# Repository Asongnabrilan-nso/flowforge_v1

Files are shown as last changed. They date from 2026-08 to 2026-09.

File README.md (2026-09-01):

# FlowForge

**Demo Video**

Demo (https://youtu.be/iGiAu_VeJ9w)

**An open-source 3D printing pen built entirely from waste.**

A handheld filament extrusion pen assembled from parts rescued from a decommissioned FDM 3D printer — hot end, nozzle, extruder mechanism, NEMA 17 stepper, PTFE tube and the printer's own Arduino Mega + RAMPS controller — and fed with filament drawn from discarded PET bottles. Every printed structural part is designed to print on the same recycled filament the pen itself consumes.

Waste plastic becomes a tool that draws in waste plastic.

## Repository layout

| Path | Contents |
|---|---|
| `firmware/` | PlatformIO project — Arduino Mega 2560 + RAMPS 1.6. See [`firmware/README.md`](firmware/README.md) |
| `stl/` | Printable parts: electronics unit enclosure and pen assembly |
| `doc/` | Project documentation and publication plan |

## The system

<p align="center">
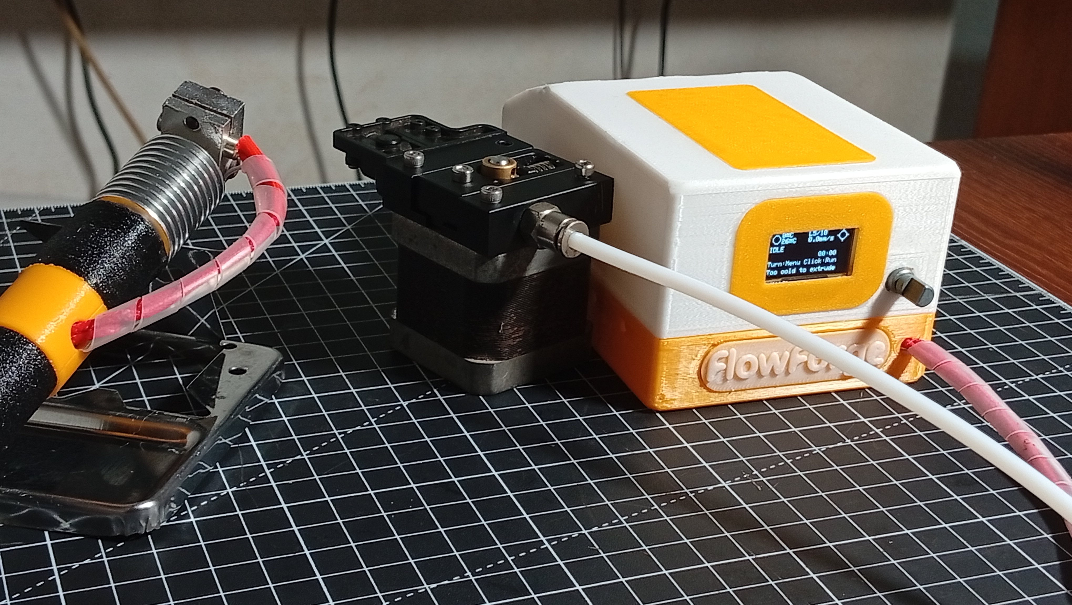
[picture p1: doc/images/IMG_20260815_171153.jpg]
  
</p>

Three units, not one object:

1. **The pen** — hot end, nozzle and vented barrel in a heat-isolated handle. No electronics beyond the heater cartridge, thermistor and fan.
2. **The electronics unit** — a 120 × 80 mm desktop wedge housing the Mega + RAMPS, the extruder stepper and driver, the OLED and the rotary encoder. Filament enters at the rear and leaves through a PTFE tether to the pen.
3. **A 24 V bench supply.**

## Sample products printed uinsing our filaments
<p align="center">
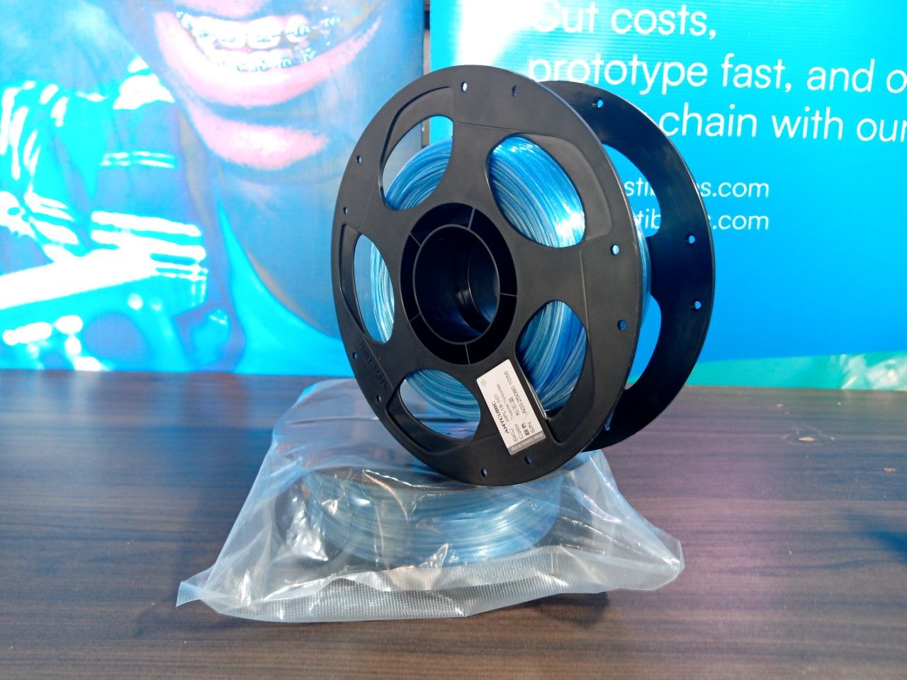
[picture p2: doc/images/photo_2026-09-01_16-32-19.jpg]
  
</p>

<p align="center">
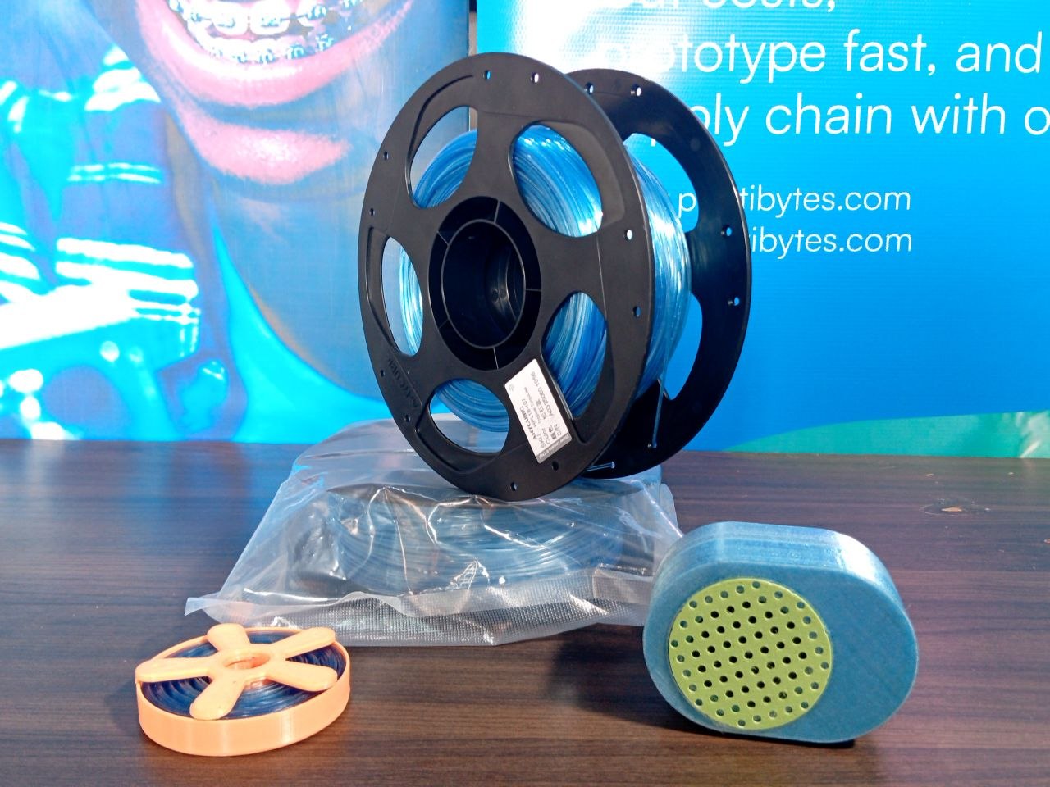
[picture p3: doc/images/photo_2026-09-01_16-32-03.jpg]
  
</p>

<p align="center">
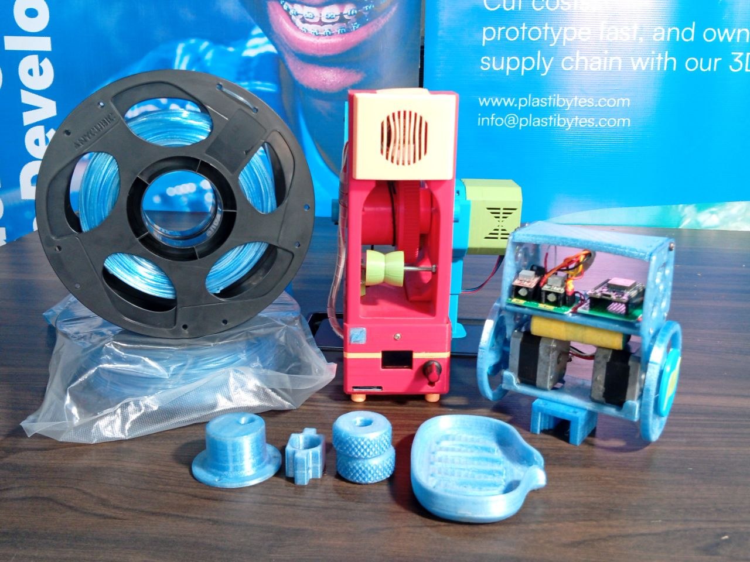
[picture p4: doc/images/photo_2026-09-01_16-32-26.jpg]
  
</p>

## Firmware at a glance

Closed-loop PID hotend control with Marlin-style thermal-runaway protection, an acceleration-ramped extruder, and a single-knob menu UI on a 128 × 64 OLED.

```sh
cd firmware
pio run              # build
pio run -t upload    # build + flash over USB
```

Safety behaviour worth knowing before you power one on:

- **The machine boots idle** — target 0 °C, motor disabled. Nothing heats until you set a target.
- **The motor will not start below 170 °C** (cold-extrusion interlock).
- **Four independent thermal faults latch until power cycle**: sensor open/short, over-temperature ceiling (260 °C), no-rise watchdog while heating, and post-settle drift watchdog.
- **Long-press the encoder from anywhere** for an immediate motor stop.

Full detail in [`firmware/README.md`](firmware/README.md).

## Licence

CERN-OHL-S v2 (hardware) · MIT (firmware).

## Status

Pre-publication. The documentation carries **[MEASURE]** markers wherever bench data is still outstanding — see the *Document maintenance* section at the end of `doc/flowforge-documentation.md` for the current list of unresolved items.

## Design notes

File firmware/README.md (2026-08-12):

# FlowForge Firmware

Firmware for a hand-built plastic-bottle-extruder machine: Arduino Mega 2560
+ RAMPS 1.6, one hotend (thermistor + PID-controlled heater cartridge), one
E0 stepper (A4988) feeding the extruder screw/gear, an SSD1306 128x64 OLED,
and an HW-040 rotary encoder for input.

The temperature control and menu/display are deliberately modeled on
Marlin's approach (PID shape, thermal-runaway watchdogs, hierarchical
click-to-navigate menu, status-screen layout) collapsed down to what this
single-hotend, single-motor machine actually needs — this is a small
hand-rolled firmware, not a Marlin build.

## Safety-relevant behavior (read this first)

- **The machine boots idle.** On power-up the heater target is 0°C (room
  temperature) and the motor is disabled. Nothing heats or moves until the
  operator explicitly sets a target (Temperature menu or a preheat preset)
  and/or starts the motor. If you're used to an earlier build of this
  firmware that auto-heated to 200°C on boot, that behavior has been
  removed.
- **Cold-extrusion interlock.** The motor will not start (click on Home is
  ignored, with a short "no" beep) unless the hotend is at or above
  `TEMP_MIN_EXTRUDE_C` (170°C by default, `include/config.h`).
- **Thermal runaway watchdogs** (mirrors Marlin's approach): while actively
  heating, the temperature must rise by `WATCH_INCREASE_C` every
  `WATCH_PERIOD_MS`, or it's treated as a heater/thermistor fault. Once
  settled, if the reading drifts more than `RUNAWAY_MAX_DEVIATION_C` from
  target for longer than `RUNAWAY_TIMEOUT_MS`, that's also a fault (stuck
  heater / thermistor fell out). An open/shorted thermistor and exceeding
  `TEMP_MAX_C` (260°C) are also immediate faults.
- **A FAULT is latched.** The display shows a full-screen alert, the heater
  and motor are forced off, and the *only* way out is a power cycle — this
  is intentional, not a bug.
- **Long-press the encoder, from anywhere, to immediately stop the motor**
  (it does not touch the heater). This works even mid-menu.

## Hardware wiring (`include/pins.h`)

| Signal | Pin | Notes |
|---|---|---|
| E0 STEP | D26 | RAMPS E0 driver slot (A4988) |
| E0 DIR | D28 | |
| E0 ENABLE | D24 | active LOW (LOW = driver enabled) |
| Hotend heater | D10 | MOSFET output; software-PWM driven, see below |
| Hotend thermistor | A13 | RAMPS T0 analog input, 4.7kΩ series divider |
| OLED SDA/SCL | D20/D21 | hardware I2C (Wire), address `0x3C` |
| Encoder A / B | D35 / D37 | HW-040 quadrature, polled (not interrupt-driven) |
| Encoder button | D31 | active LOW |
| Buzzer | D33 | `tone()`, Timer2 |

The heater is driven by a slow **software PWM window** (not `analogWrite`)
because pin 10 shares Timer2 with the Arduino core's `tone()` used for the
buzzer — see the comment in `src/Heater.h` for details. The encoder is
**polled** every `loop()` iteration rather than interrupt-driven, because
its pins (PORTC on the Mega2560) don't support pin-change interrupts — see
`src/Encoder.h`.

## Build & flash

This is a [PlatformIO](https://platformio.org/) project.

```sh
pio run                 # build
pio run -t upload       # build + flash over USB
pio device monitor       # serial monitor (115200 baud) - only used for a
                          # boot-time warning if the OLED doesn't ACK on I2C
```

Libraries (`platformio.ini`): Adafruit SSD1306, Adafruit GFX, Adafruit
BusIO — PlatformIO fetches these automatically on first build.

## Menu map

```
Home (status screen)
 |-- rotate  -> Main Menu
 |-- click   -> start/stop the extruder motor (instant, only if hot enough)
 `-- long-press (from anywhere) -> immediate motor stop

Main Menu
 |-- Back           -> Home
 |-- Temperature     -> Temperature Menu
 |-- Motor Speed     -> Set Motor Speed (edit screen)
 `-- Settings        -> Settings Menu (read-only)

Temperature Menu
 |-- Back            -> Main Menu
 |-- Nozzle           -> Set Temperature (edit screen)
 |-- Preheat PET      -> sets target to PREHEAT_PET_C (250C) immediately
 |-- Preheat HDPE     -> sets target to PREHEAT_HDPE_C (200C) immediately
 `-- Cooldown         -> sets target to 0

Settings Menu (read-only calibration readout)
 |-- Back            -> Main Menu
 |-- Steps/mm         -> EXTRUDER_STEPS_PER_MM
 |-- Max speed        -> EXTRUDER_FEEDRATE_MAX_MM_S
 `-- Accel            -> EXTRUDER_ACCEL_MM_S2

Set Temperature (edit screen)
 |-- rotate  -> adjust target by TEMP_STEP_C, clamped [0, TEMP_MAX_C]
 `-- click   -> confirm, return to Temperature Menu

Set Motor Speed (edit screen)
 |-- rotate  -> adjust speed level, clamped [SPEED_LEVEL_MIN, SPEED_LEVEL_MAX]
 `-- click   -> confirm, return to Main Menu
```

Every menu's row 0 is always **Back**, one level up — the top-level Back
(Main Menu) returns to Home. Every screen but Home is reached only by
rotating into the menu; **Home's click always toggles the motor directly**
and never enters the menu — this is a deliberate shortcut for fast,
glove-friendly start/stop on a handheld device, kept even though it departs
from Marlin (which only starts jobs through a menu action).

## Motor calibration (steps/mm)

The extruder speed is expressed in real units (mm/s of filament fed),
computed from `EXTRUDER_STEPS_PER_MM` in `include/config.h`. The shipped
default (500 steps/mm) is a **placeholder** — it depends on your motor's
steps/rev, the A4988 microstepping set by the RAMPS jumpers, and your
gear/pulley ratio, none of which this firmware can know on its own.

To calibrate:
1. Go to **Main Menu → Motor Speed** and set a known level (level 5 is a
   good midpoint).
2. Start the motor from Home (heat up past `TEMP_MIN_EXTRUDE_C` first) and
   let it run for a fixed, measured time — e.g. exactly 60 seconds — then
   stop it.
3. Measure how much filament actually came out, in mm.
4. Compute the commanded distance for that run: `commanded_mm =
   levelToFeedrateMmS(level) * seconds_run` (with the defaults, level 5 ≈
   2.0mm/s, so 60s ≈ 120mm commanded).
5. Rescale: `new_steps_per_mm = EXTRUDER_STEPS_PER_MM * (commanded_mm /
   measured_mm)`. Update `EXTRUDER_STEPS_PER_MM` in `config.h` and reflash.

`EXTRUDER_FEEDRATE_MIN_MM_S`/`_MAX_MM_S` are deliberately conservative out
of the box — they were chosen to keep the step-interrupt rate identical to
what this firmware already ran at before this update (200–2000 steps/sec),
not Marlin's own much higher extruder defaults. Once steps/mm is calibrated
and you've confirmed the motor tracks cleanly at the current ceiling, you
can raise `EXTRUDER_FEEDRATE_MAX_MM_S` (and `EXTRUDER_ACCEL_MM_S2` if you
want a snappier ramp) — increase gradually and watch/listen for missed
steps or stalling at the top of the range before committing to a value.

## PID tuning

`include/config.h`'s `PID` section documents each constant inline
(`PID_KP`/`PID_KI`/`PID_KD`, `PID_FUNCTIONAL_RANGE_C`, `PID_K1`,
`PID_SAMPLE_MS`). The algorithm itself (`src/PID.h`) is a Marlin-style PID:
outside `PID_FUNCTIONAL_RANGE_C` of the target it just bangs the heater
full on/off (avoids integral windup while ramping from cold); inside that
band it runs proportional + anti-windup-clamped integral +
EMA-smoothed derivative-on-measurement (quieter than raw derivative, so a
single noisy thermistor ADC sample can't spike the output). The shipped
gains are a starting point for a typical salvaged RepRap-era hotend — retune
for your actual hotend's thermal mass/insulation if the response is too
sluggish or oscillates.

## Module map

| Module | Responsibility |
|---|---|
| `src/Thermistor.*` | Hotend temperature sensing |
| `src/PID.h` | Generic PID control loop |
| `src/Heater.*` | PID + thermistor + safety watchdogs → heater output |
| `src/Extruder.*` | Accel-ramped Timer1 stepper pulses for the E0 A4988 |
| `src/Encoder.*` | Polled HW-040 quadrature + button |
| `src/Buzzer.*` | Non-blocking tone sequencer |
| `src/Display.*` | SSD1306 rendering — boot logo, status screen, menus |
| `src/UI.*` | Menu state machine tying the above together |

Pin map: `include/pins.h`. Tunable constants: `include/config.h`.

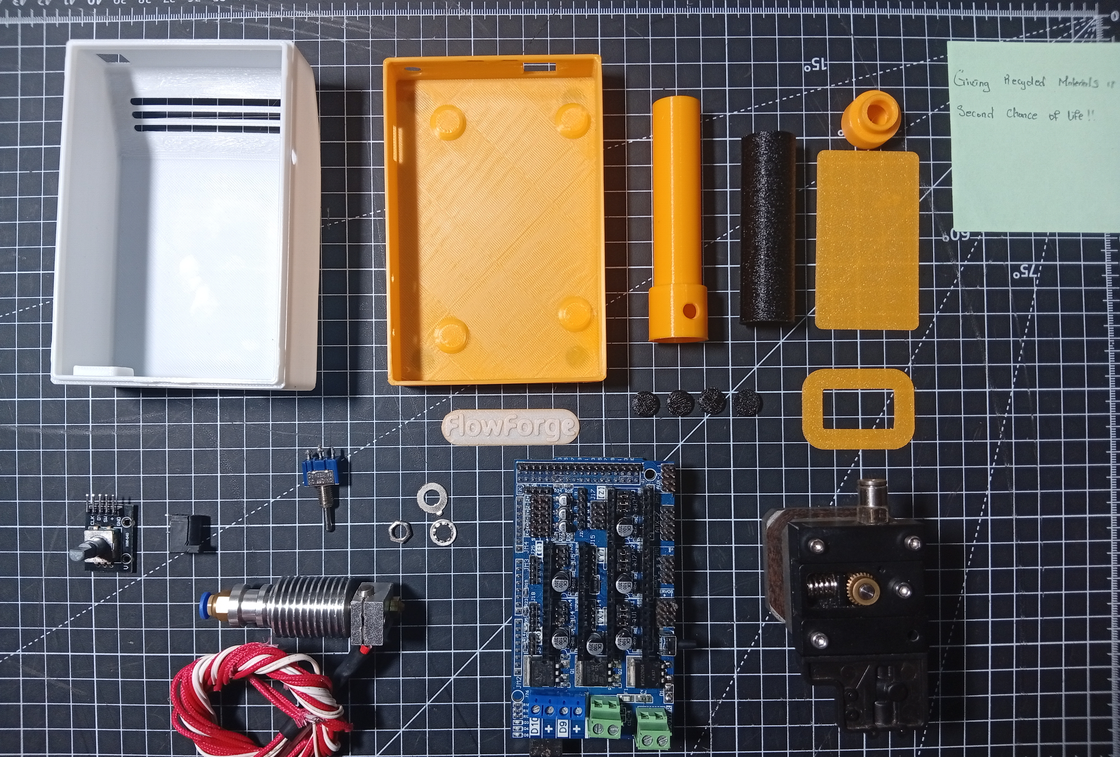
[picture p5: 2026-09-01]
doc/images/IMG_20260811_120315_modified.jpg

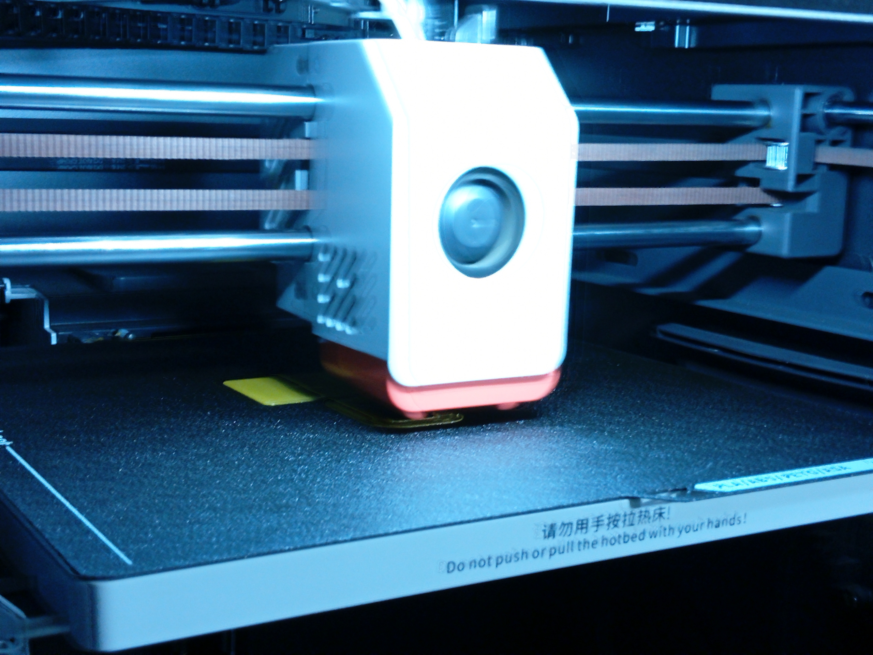
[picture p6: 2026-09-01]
doc/images/IMG_20260810_071814_NR.jpg

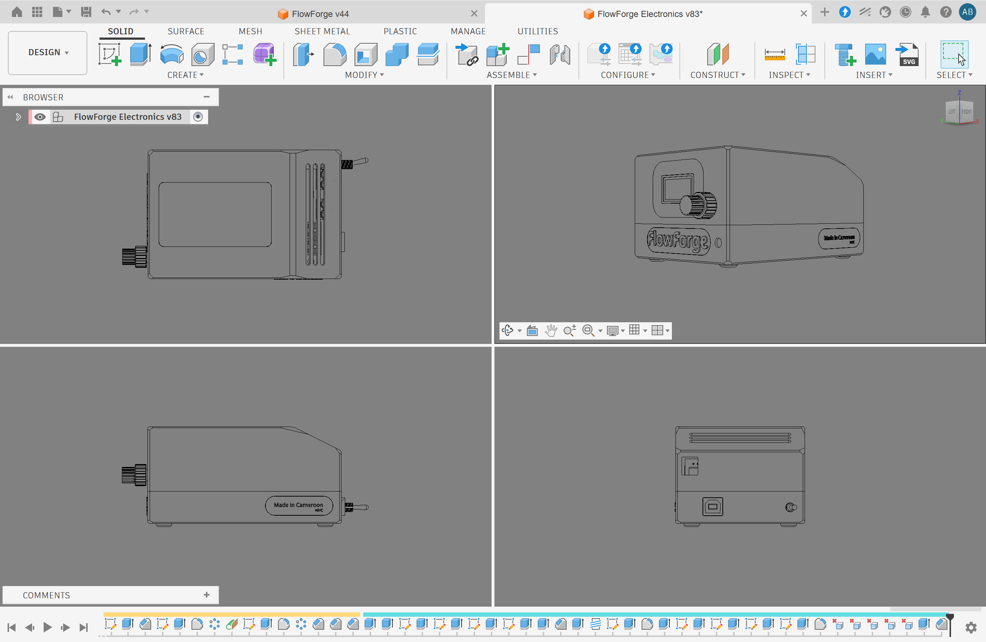
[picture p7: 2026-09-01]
doc/images/Screenshot 2026-08-19 183142.png

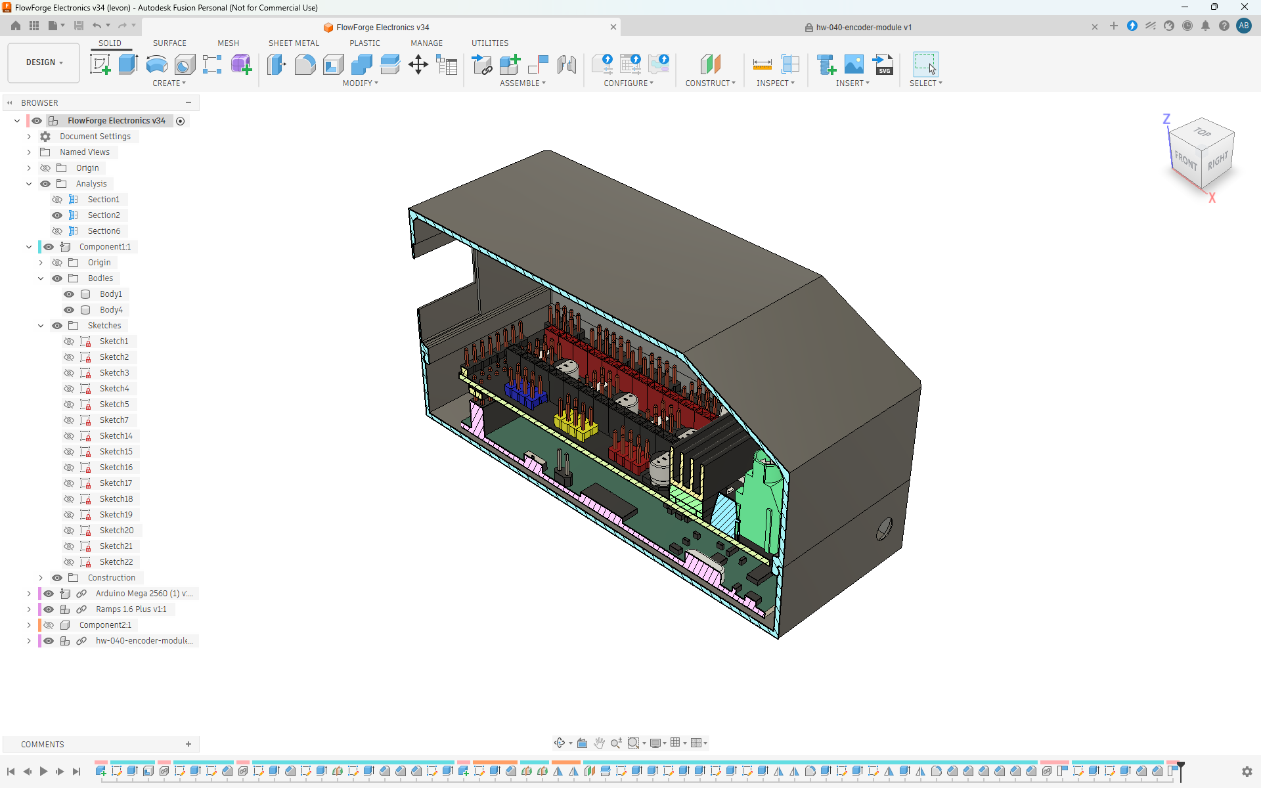
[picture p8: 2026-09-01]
doc/images/Screenshot 2026-08-06 112613.png

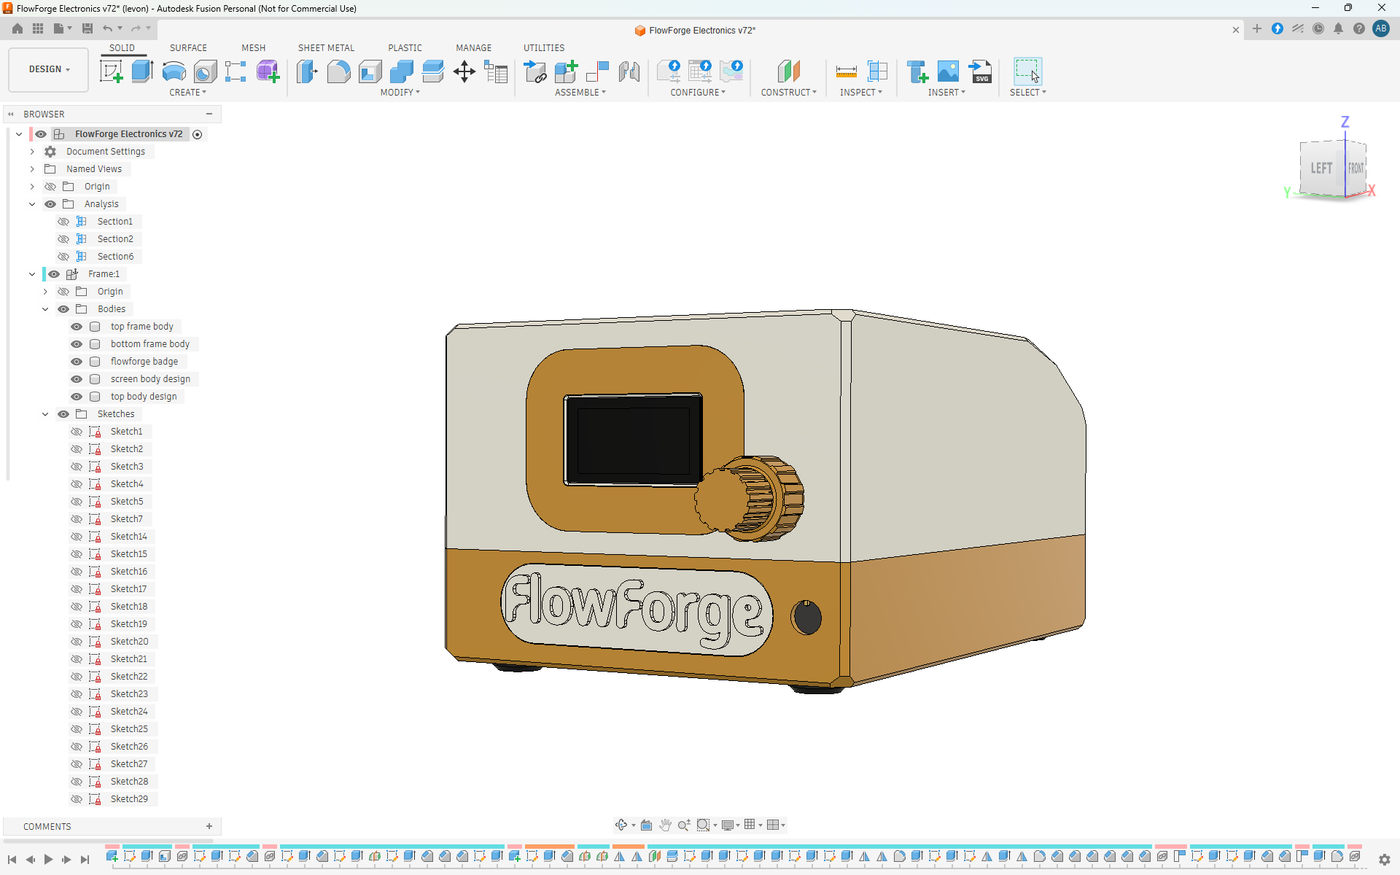
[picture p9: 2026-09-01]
doc/images/Screenshot 2026-08-10 072842.png

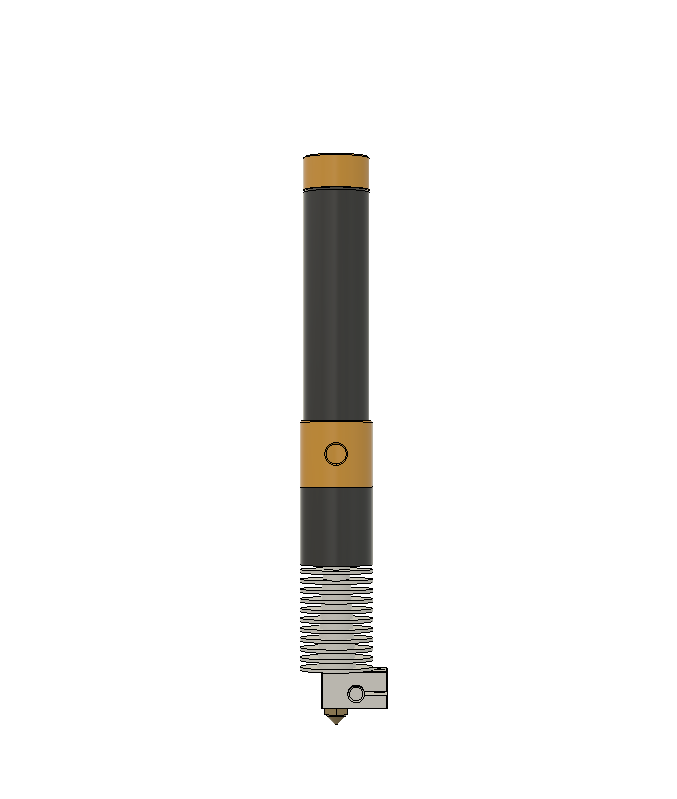
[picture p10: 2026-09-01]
doc/images/Screenshot 2026-08-12 230443.png

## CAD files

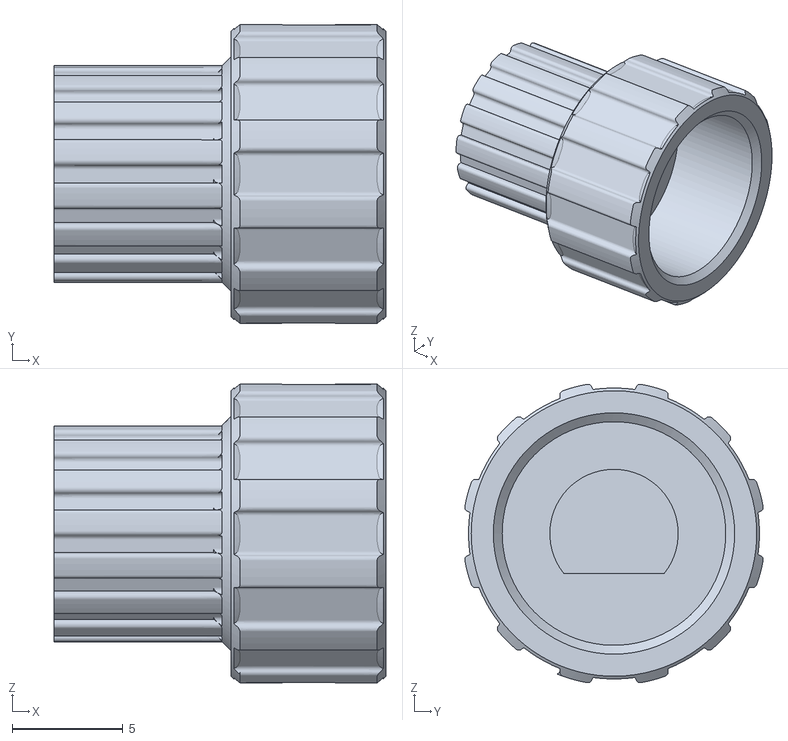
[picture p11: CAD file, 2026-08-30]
stl/rotatory encoder knob.stl
15.0 x 13.5 x 13.5

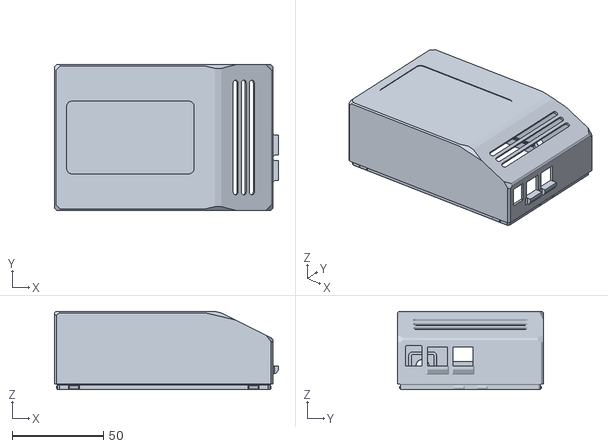
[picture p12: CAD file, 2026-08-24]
stl/top frame body.stl
123.0 x 80.0 x 43.0

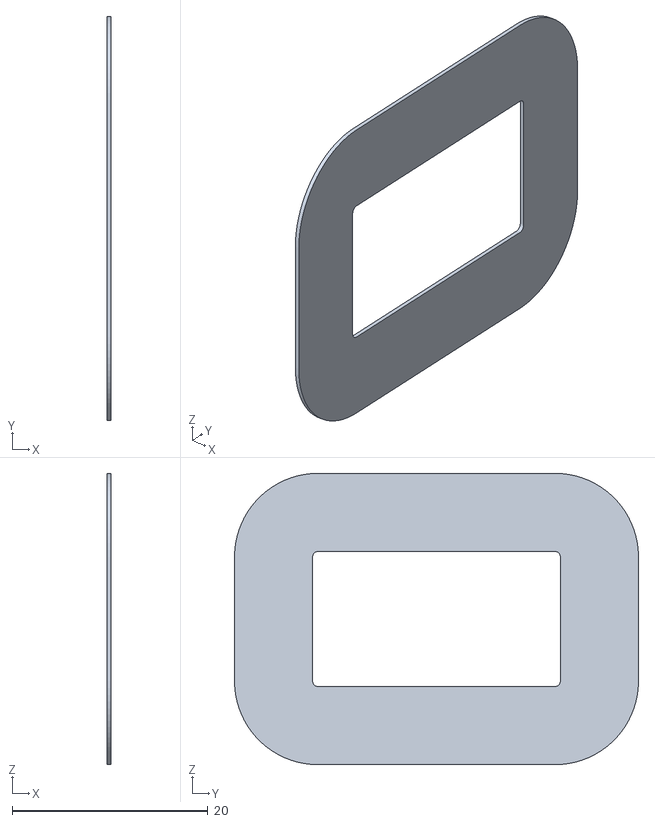
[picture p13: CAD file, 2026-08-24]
stl/screen body design.stl
0.4 x 41.3 x 29.8

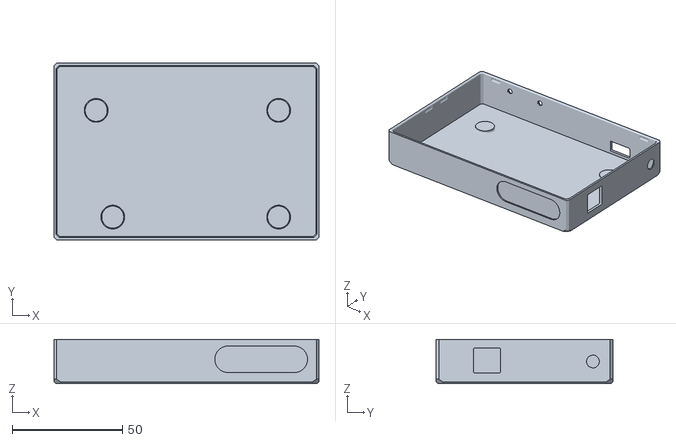
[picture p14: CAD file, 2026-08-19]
stl/bottom frame body.stl
120.0 x 80.0 x 20.0

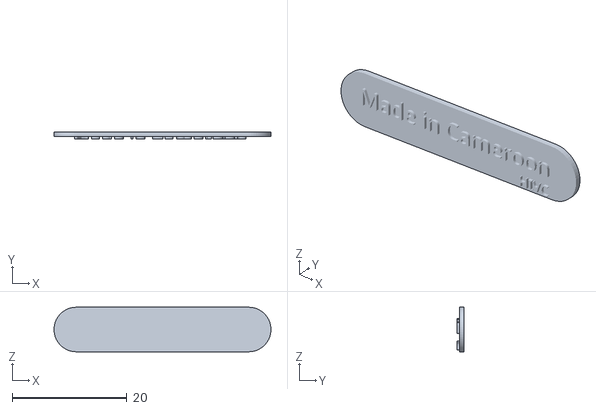
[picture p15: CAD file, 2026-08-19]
stl/made in cameroon.stl
37.8 x 1.20 x 7.76

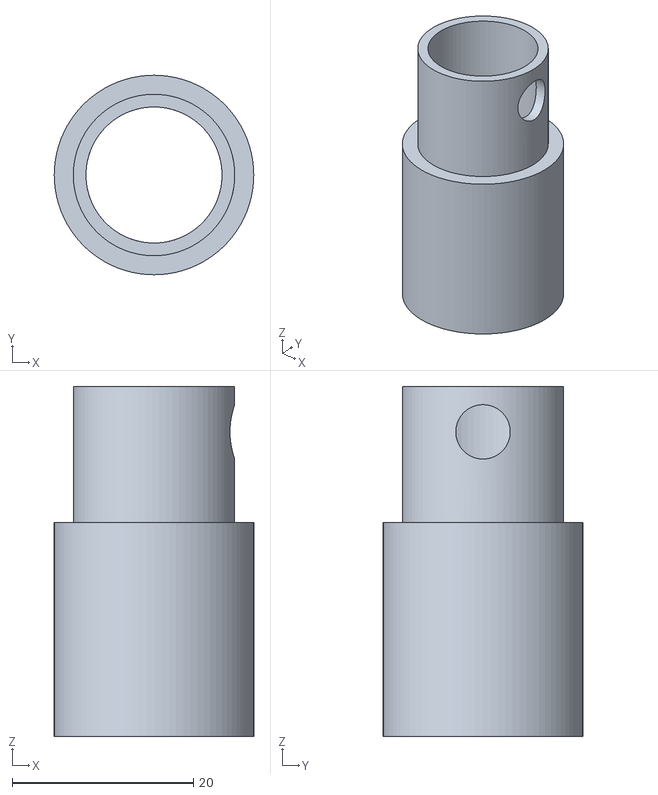
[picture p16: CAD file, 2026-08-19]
stl/hot end cover shield.stl
22.0 x 22.0 x 38.6

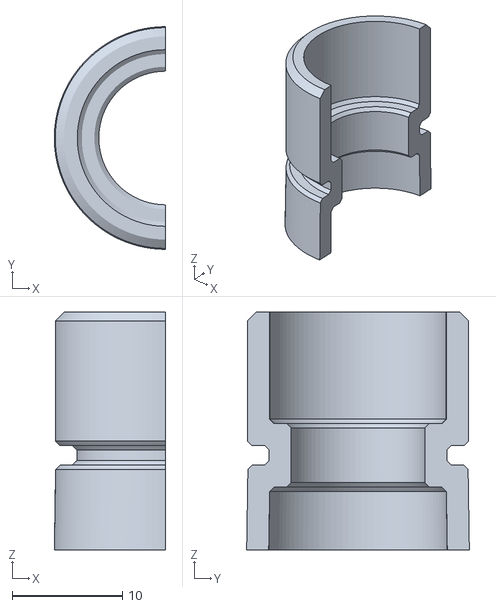
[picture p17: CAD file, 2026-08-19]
stl/hot end cover1.stl
10.1 x 20.2 x 21.6

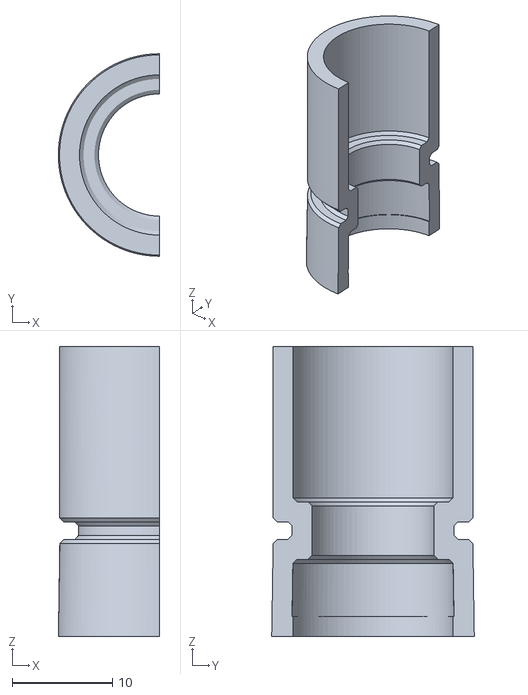
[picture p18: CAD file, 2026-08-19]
stl/Body1.stl
10.1 x 20.3 x 29.0

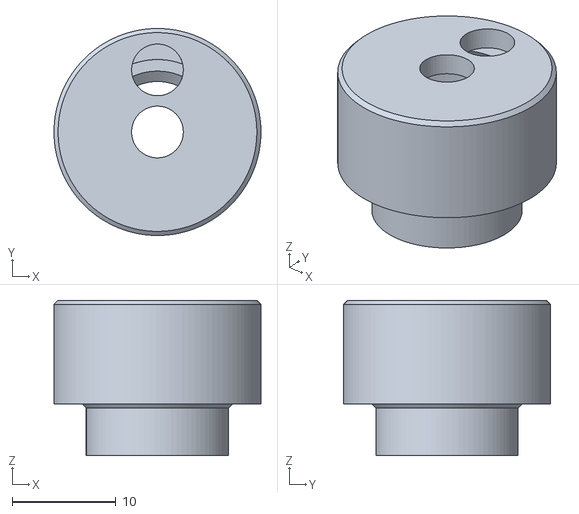
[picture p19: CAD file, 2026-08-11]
stl/top cap.stl
20.0 x 20.0 x 15.0

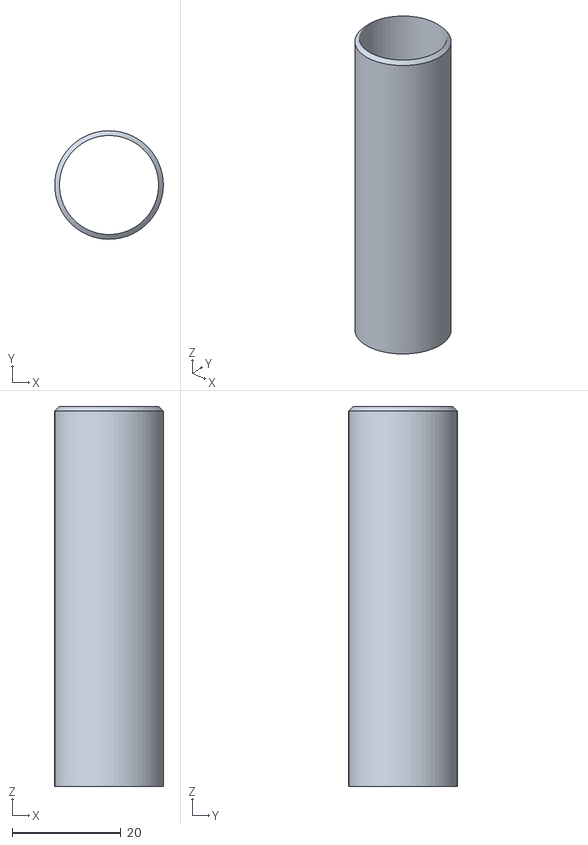
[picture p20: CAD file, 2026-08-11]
stl/handle.stl
20.0 x 20.0 x 70.0

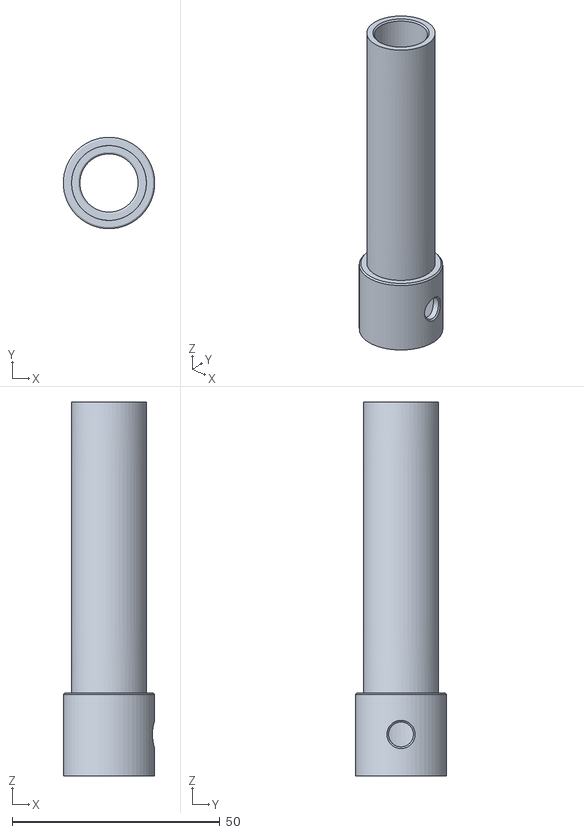
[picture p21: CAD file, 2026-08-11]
stl/body cylinder.stl
22.0 x 22.0 x 90.0

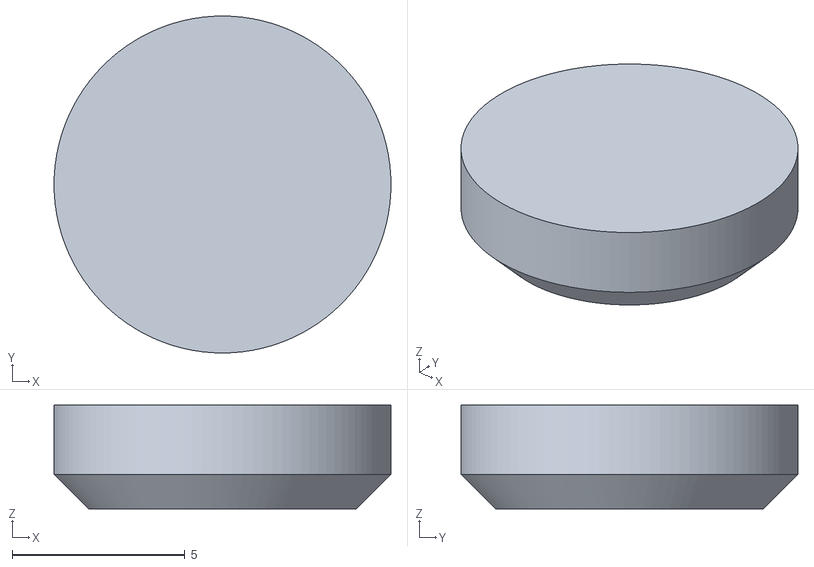
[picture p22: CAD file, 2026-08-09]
stl/bottom support.stl
9.76 x 9.76 x 3.00

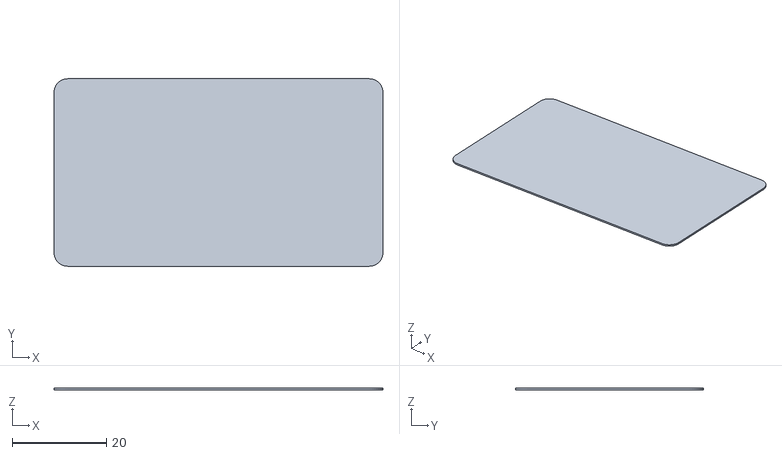
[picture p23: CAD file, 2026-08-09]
stl/top body design.stl
69.8 x 39.8 x 0.4

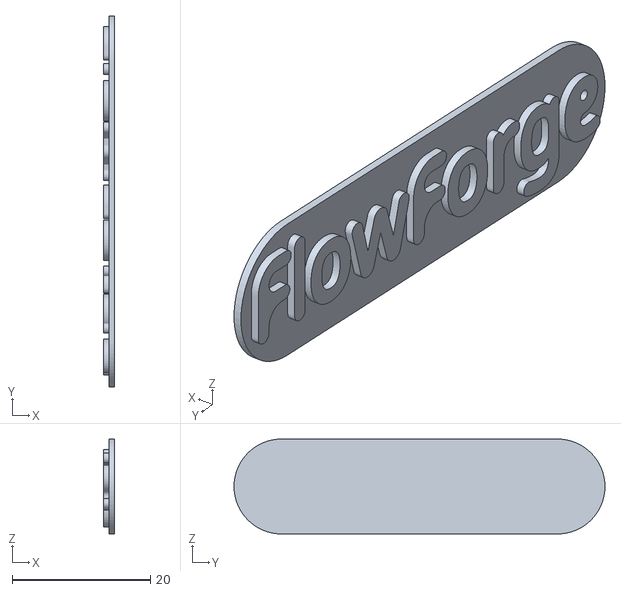
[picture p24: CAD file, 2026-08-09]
stl/flowforge badge.stl
1.60 x 53.8 x 13.8

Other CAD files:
stl/hot end cover2.stl

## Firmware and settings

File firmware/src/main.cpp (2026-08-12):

// FlowForge firmware - Arduino Mega 2560 + RAMPS 1.6
// Hand-held 3D printing pen built from recycled materials.
//
// Module map:
//   Thermistor  - hotend temperature sensing (src/Thermistor.*)
//   PID         - generic PID control loop (src/PID.h)
//   Heater      - PID + thermistor + safety watchdogs -> heater output (src/Heater.*)
//   Extruder    - Timer1-driven, accel-ramped stepper pulses for the E0 A4988 (src/Extruder.*)
//   Encoder     - polled HW-040 quadrature + button (src/Encoder.*)
//   Buzzer      - non-blocking tone sequencer (src/Buzzer.*)
//   Display     - SSD1306 rendering, boot logo + UI screens (src/Display.*)
//   UI          - menu state machine tying the above together (src/UI.*)
//
// Pin map: include/pins.h   Tunable constants: include/config.h

#include <Arduino.h>
#include "../include/pins.h"
#include "../include/config.h"
#include "Thermistor.h"
#include "Heater.h"
#include "Extruder.h"
#include "Encoder.h"
#include "Buzzer.h"
#include "Display.h"
#include "UI.h"

Thermistor hotendThermistor(TEMP_0_PIN);
Heater hotendHeater(HEATER_0_PIN, hotendThermistor);

void setup() {
    buzzer.begin(BEEPER_PIN);
    encoder.begin();
    extruder.begin();
    hotendHeater.begin();

    bool oledOk = display.begin();
    display.showBootScreen();
    buzzer.bootChime();

    if (!oledOk) {
        // Nothing more we can show the user - fall back to a serial hint in
        // case a debug console is attached.
        Serial.begin(115200);
        Serial.println(F("SSD1306 not found at configured I2C address"));
    }

    ui.begin(hotendHeater);
}

void loop() {
    hotendHeater.update();
    extruder.update(); // advances the accel ramp every iteration
    ui.update();
}

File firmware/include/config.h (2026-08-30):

#pragma once
// User-tunable constants for FlowForge. Grouped by subsystem so calibration
// doesn't require touching the driver code.

// ================= Thermistor =================
// Generic 100K NTC (beta ~3950), matches most salvaged RepRap-era hotends
// incl. JGAurora A5. Retune THERMISTOR_BETA if you have exact datasheet
// values - everything downstream (PID, safety limits) is in degrees C and
// doesn't care how the raw ADC was converted.
#define THERMISTOR_BETA        3950.0f
#define THERMISTOR_R0_OHMS     100000.0f  // resistance at THERMISTOR_T0_C
#define THERMISTOR_T0_C        25.0f
#define THERMISTOR_SERIES_OHMS 4700.0f    // RAMPS onboard divider resistor
#define THERMISTOR_OVERSAMPLE  8          // ADC samples averaged per reading

// ================= Safety =================
#define TEMP_MAX_C            260.0f  // absolute ceiling -> immediate fault
#define TEMP_MIN_EXTRUDE_C    170.0f  // cold-extrusion prevention threshold
#define TEMP_AT_TARGET_TOL_C  3.0f    // "reached target" tolerance

// Thermal runaway watchdog (same idea as Marlin's WATCH_TEMP_PERIOD): while
// heating, temperature must rise by at least WATCH_INCREASE_C every
// WATCH_PERIOD_MS, otherwise something is wrong (disconnected heater/
// thermistor, thermistor fell out of the block, etc).
#define WATCH_PERIOD_MS        20000UL
#define WATCH_INCREASE_C       2.0f

// Once at temperature, if the reading drifts away from target by more than
// this for longer than RUNAWAY_TIMEOUT_MS, latch a fault (stuck heater).
#define RUNAWAY_MAX_DEVIATION_C 15.0f
#define RUNAWAY_TIMEOUT_MS      10000UL

// ================= PID =================
// Starting values only - tune for your specific hotend mass/insulation.
#define PID_KP  22.0f
#define PID_KI  1.5f
#define PID_KD  110.0f
#define PID_OUTPUT_MIN   0
#define PID_OUTPUT_MAX   255
#define PID_SAMPLE_MS    250UL   // PID + heater window update period

// Marlin-style PID_MAX derating: cap the heater's ACTUAL output ceiling
// below the raw 0-255 PWM range so it is never driven at indefinite 100%
// duty (continuous full-rail current). The bang-bang bootstrap (PID.h) and
// the anti-windup clamp both key off this value, so capping it here caps
// both the cold-start current step and every sustained high-duty stretch
// (e.g. holding near TEMP_MAX_C, where the PID otherwise sits close to
// saturation for a long time). Salvaged RAMPS heater MOSFETs/screw
// terminals are the weak link here - this exists to keep them from cooking
// under sustained near-max current, not to protect the hotend itself.
// Lower further (e.g. 70) if your specific board still runs hot at 80%.
#define HEATER_MAX_DUTY_PCT   80
#define PID_OUTPUT_MAX_CAPPED ((uint8_t)((uint16_t)PID_OUTPUT_MAX * HEATER_MAX_DUTY_PCT / 100))

// |target - current| beyond this -> full-on/full-off bang mode instead of
// PID math (avoids integral windup while ramping from cold; mirrors
// Marlin's PID_FUNCTIONAL_RANGE).
#define PID_FUNCTIONAL_RANGE_C  15.0f
// Derivative EMA smoothing: weight retained from the previous sample
// (Marlin PID_K1). Higher = smoother/laggier, lower = snappier/noisier.
#define PID_K1                  0.95f

// ================= Temperature setpoint =================
// No default target - the heater boots idle at 0 (room temp) and only
// starts heating once the operator sets a target via the menu (manual edit
// or a preheat preset). See UI::begin().
#define TEMP_STEP_C            5.0f   // change per encoder detent
#define TEMP_SETPOINT_MIN_C    0.0f

// ================= Preheat presets =================
// One-click Temperature-menu presets for common recycled-bottle plastics
// (Marlin-style "Preheat PLA" buttons, collapsed to this machine's material mix).
#define PREHEAT_PET_C   250.0f
#define PREHEAT_HDPE_C  200.0f

// ================= Extruder motion =================
// Ported from Marlin's per-axis motion params (steps/mm, feedrate,
// acceleration), collapsed to FlowForge's single continuous-feed E0 motor.
//
// EXTRUDER_STEPS_PER_MM: retune once measured - mark 100mm of filament,
// extrude it at speed level 5, measure actual mm delivered, rescale this
// constant accordingly. Actual microstepping is set by the RAMPS A4988
// driver jumpers, not software - this constant must match whatever jumper
// config is physically installed.
#define EXTRUDER_STEPS_PER_MM      500.0f
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

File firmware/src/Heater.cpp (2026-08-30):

#include "Heater.h"
#include <math.h>
#include "../include/config.h"

Heater::Heater(uint8_t heaterPin, Thermistor& thermistor)
    : _pin(heaterPin), _thermistor(thermistor),
      // PID_OUTPUT_MAX_CAPPED, not PID_OUTPUT_MAX: derates the ceiling the
      // bang-bang bootstrap and anti-windup clamp both use, so the heater is
      // never driven at raw 100% duty for extended stretches (see config.h).
      _pid(PID_KP, PID_KI, PID_KD, PID_OUTPUT_MIN, PID_OUTPUT_MAX_CAPPED,
           PID_FUNCTIONAL_RANGE_C, PID_K1) {
}

void Heater::begin() {
    pinMode(_pin, OUTPUT);
    digitalWrite(_pin, LOW);
}

void Heater::setTarget(float celsius) {
    if (_state == HeaterState::FAULT) return; // latched - ignore until reset
    if (celsius < TEMP_SETPOINT_MIN_C) celsius = TEMP_SETPOINT_MIN_C;
    if (celsius > TEMP_MAX_C) celsius = TEMP_MAX_C;
    _target = celsius;
}

bool Heater::safeToExtrude() const {
    return _state != HeaterState::FAULT && _current >= TEMP_MIN_EXTRUDE_C;
}

void Heater::enterFault(FaultReason reason) {
    _state = HeaterState::FAULT;
    _faultReason = reason;
    _pwmOutput = 0;
    digitalWrite(_pin, LOW);
}

void Heater::update() {
    unsigned long now = millis();

    if (_state == HeaterState::FAULT) {
        digitalWrite(_pin, LOW); // belt and braces - never let this drift high
        return;
    }

    // --- Slow control loop: read sensor, run PID, decide state (every PID_SAMPLE_MS) ---
    if (now - _lastSampleMs >= PID_SAMPLE_MS) {
        _lastSampleMs = now;

        _current = _thermistor.readCelsius();
        if (_thermistor.lastReadFaulted()) {
            enterFault(FaultReason::SENSOR);
            return;
        }
        if (_current >= TEMP_MAX_C) {
            enterFault(FaultReason::OVER_TEMP);
            return;
        }

        HeaterState prevState = _state;

        if (_target <= TEMP_SETPOINT_MIN_C) {
            _state = HeaterState::IDLE;
            _pid.reset();
            _pwmOutput = 0;
        } else {
            float dtSeconds = PID_SAMPLE_MS / 1000.0f;
            float output = _pid.compute(_target, _current, dtSeconds);
            // Belt and braces: PID.h already clamps to PID_OUTPUT_MAX_CAPPED
            // internally, but constrain against the same derated ceiling
            // here too so this line can never become the one place that
            // quietly lets full 255/100% duty back in.
            _pwmOutput = (uint8_t)constrain(output, PID_OUTPUT_MIN, PID_OUTPUT_MAX_CAPPED);

            bool atTemp = fabsf(_target - _current) <= TEMP_AT_TARGET_TOL_C;
            _state = atTemp ? HeaterState::AT_TEMP : HeaterState::HEATING;
        }

        // Runaway watchdog #1: while actively heating, require steady progress.
        if (_state == HeaterState::HEATING) {
            if (prevState != HeaterState::HEATING) {
                _watchWindowStartMs = now;
                _watchWindowStartTemp = _current;
            } else if (now - _watchWindowStartMs >= WATCH_PERIOD_MS) {
                if (_current - _watchWindowStartTemp < WATCH_INCREASE_C) {
                    enterFault(FaultReason::RUNAWAY_NO_RISE);
                    return;
                }
                _watchWindowStartMs = now;
                _watchWindowStartTemp = _current;
            }
        }

        // Runaway watchdog #2: once settled, don't allow sustained drift away
        // from target (e.g. heater stuck on, or thermistor slipped out).
        if (_state == HeaterState::AT_TEMP || prevState == HeaterState::AT_TEMP) {
            float deviation = fabsf(_target - _current);
            if (deviation > RUNAWAY_MAX_DEVIATION_C) {
                if (!_drifting) {
                    _drifting = true;
                    _driftStartMs = now;
                } else if (now - _driftStartMs >= RUNAWAY_TIMEOUT_MS) {
                    enterFault(FaultReason::RUNAWAY_DRIFT);
                    return;
                }
            } else {
                _drifting = false;
            }
        }

        _windowStartMs = now; // resync PWM window to the new duty cycle
    }

    applyOutput();
}

void Heater::applyOutput() {
    unsigned long now = millis();
    unsigned long elapsed = now - _windowStartMs;
    if (elapsed >= PID_SAMPLE_MS) {
        _windowStartMs = now;
        elapsed = 0;
    }
    unsigned long onTime = ((unsigned long)_pwmOutput * PID_SAMPLE_MS) / 255UL;
    digitalWrite(_pin, elapsed < onTime ? HIGH : LOW);
}

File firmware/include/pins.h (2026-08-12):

#pragma once
// Pin map for FlowForge on Arduino Mega 2560 + RAMPS 1.6.
// Only the signals FlowForge actually uses are defined here - the rest of
// the RAMPS wiring diagram (X/Y/Z, other heaters/fans, endstops) is unused.

// ---- Extruder stepper (E0 driver slot, A4988) ----
#define E0_STEP_PIN     26
#define E0_DIR_PIN      28
#define E0_ENABLE_PIN   24   // active LOW: LOW = driver enabled

// ---- Hotend ----
#define HEATER_0_PIN    10   // hotend cartridge heater MOSFET
#define TEMP_0_PIN      A13  // hotend thermistor (RAMPS T0 input)

// ---- OLED / encoder panel (TinyBoy2-style, RAMPS AUX-2/AUX-4 header) ----
// OLED is I2C on the Mega's hardware I2C bus (SDA=20, SCL=21) - the Wire
// library uses these automatically, no explicit pin defines needed.
#define BTN_EN1_PIN     35   // encoder quadrature A
#define BTN_EN2_PIN     37   // encoder quadrature B
#define BTN_ENC_PIN     31   // encoder push-button
#define BEEPER_PIN      33   // buzzer

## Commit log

2026-08-09 added README.md
    [bottom frame body.stl, bottom support.stl, flowforge badge.stl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]
2026-08-11 updated stl file
    [body cylinder.stl, bottom frame body.stl, handle.stl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]
2026-08-19 updated firmware
    [Body1.stl, bottom frame body.stl, hot end cover shield.stl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]
2026-08-24 updated stl files
    [screen body design.stl, top frame body.stl]
